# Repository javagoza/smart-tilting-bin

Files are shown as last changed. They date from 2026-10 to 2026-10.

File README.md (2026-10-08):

# Smart Tilting Bin

A refuse sorter that sees, hears and learns, built with reused materials.

A camera looks down at the object you drop in, an AI model decides which of four fractions it belongs to (packaging, paper, organic, general waste), and a rotating-tilting tray drops it into the right container. Two small motors reach four containers.

> Work in progress. This repository holds the parametric mechanical model and the simulation. It is part of my application to the element14 "My Project Is Trash" design challenge. Software and results will be added as the project advances.

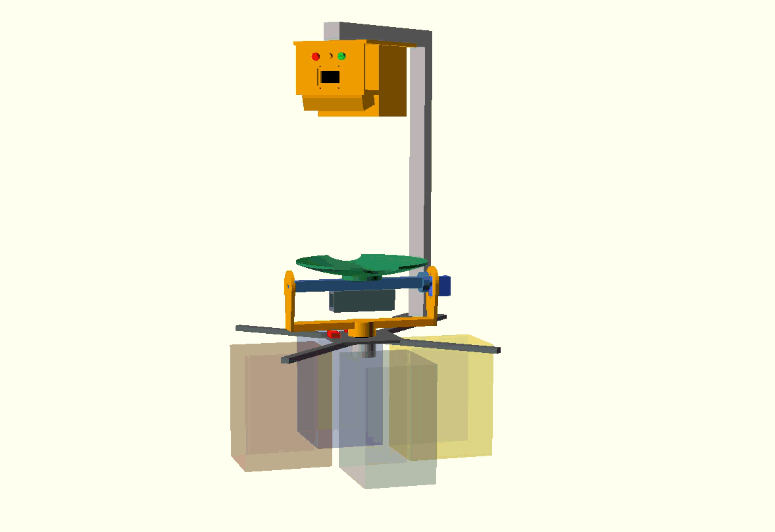
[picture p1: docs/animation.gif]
Sorting animation


## How it works

1. The user drops an object onto the tray, which rests horizontally.
2. An impact triggers a capture: a top-down Logitech C170 takes a photo and its microphone records the impact sound.
3. A Raspberry Pi CM4 classifies image and sound and maps the class to one of the four containers.
4. If the container is in line with the current tray position, the tray only tilts to +45 or -45 degrees. Otherwise the stepper first rotates the tray 90 degrees, stops, and then the tray tilts to the correct side.
5. The object slides through one of the two bites in the tray rim and falls into the container.
6. The tray returns to horizontal and LEDs and an OLED report the result.

```
               [ PAPER ]
                   |
 [ PACKAGING ] --- O --- [ ORGANIC ]
                   |
            [ GENERAL WASTE ]

 O = tray axis. At rotation 0 the tray tilts towards PAPER or
 GENERAL WASTE, at rotation 90 towards PACKAGING or ORGANIC.
```

## Mechanism

- **Base:** a fixed plate holds a 28BYJ-48 stepper (ULN2003 driver) with a vertical shaft. There is no solid disc under the tray, so objects fall freely.
- **Yoke:** a U-shaped yoke on the stepper shaft rotates between 0 and 90 degrees (two microswitches provide homing) and carries the tilt axis and an SG90 servo.
- **Tilt axis:** a horizontal beam. One end is a simple pivot and the other is coupled directly to the servo horn, so 90 degrees of servo travel gives +/-45 degrees of tilt.
- **Tray:** 150 mm, concave, with two round bites on the rim, perpendicular to the tilt axis.
- **Counterweight:** a printed holder under the beam with a sliding steel bar, so the servo hardly works at rest and the tray settles horizontal by itself.
- **Sensor support:** an "L" or arch bolted to a diagonal strut holds the camera above the tray. Its front wall faces the user and carries three LEDs, an OLED and, underneath, the IR light angle sensor aimed at the tray.

## Hardware

| Part | Role |
|---|---|
| Analog Devices EVAL-ADXL372Z | Vandalism and heavy-object protection, capture trigger, impact signature |
| Analog Devices EVAL-CN0569-PMDZ | IR gesture selection of the bin, labelling, game controller, hand detection |
| Hammond 1554X2GYCL (IP68) | Sealed enclosure for the electronics |
| CamdenBoss IND514113-LED | Green, amber and red status LEDs |
| CamdenBoss CTBP92HD/4 and CTBP93HD/4 | Pluggable terminal blocks |
| CamdenBoss CSM40500A | Limit switches for homing |

Complementary hardware (not in the kit): Raspberry Pi CM4 on a Waveshare CM4-NANO-A (or Pi 4 / Pi 5), Logitech C170, 28BYJ-48 with ULN2003, SG90 servo and an SSD1306 OLED.

## OpenSCAD model

Open `cad/smart_tilting_bin.scad` with OpenSCAD 2021.01 or later. Every dimension is a variable, so you can adapt the model to the materials you find (a salad bowl as the tray, a curtain-rod tube as the beam, and so on).

Main parameters:

| Parameter | Meaning |
|---|---|
| `part` | `"assembly"`, `"tray"`, `"beam"`, `"yoke"`, `"base"`, `"counterweight"` or `"camera_support"` (to export single STL files) |
| `yaw` | Tray rotation, 0 to 90 degrees |
| `tilt` | Tray tilt, -45 to +45 degrees |
| `animate` | `true` runs the sorting simulation of the four refuse types (View > Animate) |
| `show_bins`, `show_hw`, `show_cam` | Show containers, electronics and the camera support |
| `cam_support` | `"L"` or `"arch"` |
| `tray_d`, `dish_depth`, `bite_r` | Tray diameter, concavity and bite radius |
| `cw_bar_len` | Counterweight bar length (the console prints an estimate of the balance) |
| `cam_view_d` | Diameter of the tray area the camera must see |

The console prints the estimated balance of the tray, the camera height and the aim angle of the IR sensor.

Dimensions of the commercial parts (28BYJ-48, SG90, Logitech C170, SSD1306) are typical values, so check them against your own parts.

## Render the animation

With OpenSCAD and ffmpeg installed:

```
./scripts/render_gif.sh
```

Or with the OpenSCAD GUI: set `animate = true`, open View > Animate with 160 steps and 20 FPS, check "Dump Pictures", and turn the PNG frames into a GIF with ffmpeg.

## Reusing materials

Most of the mechanism can be built from waste: a plastic bowl or wok lid as the tray, a curtain-rod tube as the tilt beam, a cutting board or pallet wood for the base, a bottle cap as the sliding washer, a paper tube as the sensor visor, a food container lid as the LED panel, and nuts and bolts as the counterweight. Motors, servo, sensors and electronics are new.

## Status

- [x] Parametric OpenSCAD model and sorting simulation
- [ ] Mechanism build and calibration
- [ ] Electronics and wiring
- [ ] Vision classifier (offline and online)
- [ ] Sound classifier and sensor fusion
- [ ] Gesture selection, labelling and game mode
- [ ] Vandalism detection

## License

- CC BY-SA 4.0 for the CAD files 
- MIT for the code

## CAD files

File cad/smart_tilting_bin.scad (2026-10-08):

/*
 * SMART TILTING BIN - computer-vision refuse sorter
 * Rotating-tilting tray mechanism (first prototype)
 *
 * Mechanical concept
 * ------------------
 *  - Fixed BASE: a central plate holds the 28BYJ-48 stepper (vertical shaft) and
 *    4 diagonal struts towards the enclosure. There is no disc under the tray,
 *    so objects fall freely into the containers.
 *  - YOKE (rotation): a U-shaped bar fixed to the 28BYJ-48 shaft. It only turns
 *    between 0 and 90 degrees (two microswitches provide homing at those two
 *    positions) and carries the SG90 servo and the tilt axis.
 *  - BEAM + TRAY (tilt): the horizontal beam is the tilt axis. One end is a
 *    simple pivot, the other is coupled to the SG90 horn (direct drive,
 *    90 degrees of servo travel = +/-45 degrees of tilt).
 *  - The tray is concave (parabolic) and has 2 "bites" on the sides where the
 *    refuse falls (perpendicular to the tilt axis). They work as a funnel
 *    towards the container. The ends of the tilt axis keep a solid rim.
 *  - 4 containers at 0/90/180/270 degrees around the axis (translucent ghosts).
 *  - COUNTERWEIGHT: a holder under the beam with a sliding steel bar.
 *  - "L" or "arch" SUPPORT (cam_support) for the overhead Logitech C170 camera,
 *    bolted to a diagonal strut of the base. Its front wall (user side) carries
 *    3 x 8 mm LEDs, below them the SSD1306 OLED (not in the kit) with an acrylic
 *    window and, under a lower shelf, the IR light angle sensor tilted towards
 *    the tray (ir_aim). The OLED shows the gestures to perform and the IR sensor
 *    can also detect a hand approaching to drop refuse.
 *
 * Positioning logic (the +/-45 degree tilt reaches 2 containers for each yaw):
 *    yaw 0   -> tilt +/-45 reaches the containers at 90 and 270 degrees (+/-Y)
 *    yaw 90  -> tilt +/-45 reaches the containers at 0 and 180 degrees  (+/-X)
 *    If the target container is already "in front" of the current position the
 *    tray only tilts. Otherwise it rotates 90 degrees, stops and then tilts.
 *
 * Convention: positive yaw = counterclockwise seen from above.
 *             positive tilt = the +Y side goes up (refuse falls towards -Y).
 *
 * Units: mm.
 * Usage: change `part` to export single parts to STL.
 *        Set `animate = true` and use View > Animate (FPS 20, Steps 400) to run
 *        the sorting simulation of the four refuse types.
 *
 * Dimensions of the commercial parts (28BYJ-48, SG90, Logitech C170, SSD1306)
 * are typical values: check them against your own parts.
 */

// ------------------------------------------------------------------ PARAMETERS
part        = "assembly";   // "assembly","tray","beam","yoke","base","counterweight","camera_support"
yaw         = 0;            // [0:90]    tray rotation (28BYJ-48)
tilt        = 0;            // [-45:45]  tray tilt (SG90)
animate     = false;        // true: refuse deposition simulation (View > Animate)
show_bins   = true;         // ghost containers
show_hw     = true;         // motor, servo, horn, microswitches, sensors

$fn = 90;

// ------------------------------------------------ REFUSE DEPOSITION SIMULATION
// Container i sits at angle 90*i: 0=+X Packaging, 1=+Y Paper, 2=-X Organic, 3=-Y General waste
bin_names = ["Packaging","Paper","Organic","General waste"];
seq = [1,3,0,2];   // demo order: Paper, General waste (no rotation), Packaging (rotates 90), Organic (no rotation)

function yaw_for(i)  = (i==0 || i==2) ? 90 : 0;     // containers on X -> yaw 90
function tilt_for(i) = (i==0 || i==3) ? 45 : -45;   // tilt + : refuse falls towards the local -Y side
function clamp01(x)  = min(max(x,0),1);
function ease(x)     = let(c = clamp01(x)) c*c*(3-2*c);

// Timeline: $t in [0,1) -> 4 refuse items, each with its phases (u in [0,1)):
//  0.00-0.12 the item drops onto the tray        0.12-0.25 computer vision (identifies it)
//  0.25-0.40 rotation of 90 deg if needed (stop) 0.40-0.56 tilt to +/-45 deg
//  0.52-0.68 the item slides through the bite    0.68-0.86 falls into the container
//  0.72-0.88 the tray returns to 0 deg           0.90-1.00 (last item) yaw returns to 0 (rest)
sim_k   = min(floor($t*4), 3);
sim_u   = $t*4 - sim_k;
sim_bin = seq[sim_k];
sim_prev_yaw = sim_k==0 ? 0 : yaw_for(seq[sim_k-1]);
sim_yaw_raw  = sim_prev_yaw + (yaw_for(sim_bin)-sim_prev_yaw)*ease((sim_u-0.25)/0.15);
sim_yaw  = sim_k==3 ? sim_yaw_raw*(1-ease((sim_u-0.90)/0.10)) : sim_yaw_raw;
sim_tilt = tilt_for(sim_bin)*(ease((sim_u-0.40)/0.16) - ease((sim_u-0.72)/0.16));

yaw_e  = animate ? sim_yaw  : yaw;
tilt_e = animate ? sim_tilt : tilt;

// Refuse kinematics
orad   = 8;                                  // approximate size of each refuse item
function zloc(d) = beam_h/2 + hub_h + zs(d) + tray_t + orad;
function rx(p,a) = [p[0], p[1]*cos(a)-p[2]*sin(a), p[1]*sin(a)+p[2]*cos(a)];
function rz(p,a) = [p[0]*cos(a)-p[1]*sin(a), p[0]*sin(a)+p[1]*cos(a), p[2]];
function world_pos(yw,tl,lp) = rz(rx(lp,tl)+[0,0,Zt], yw);
function rest_pos(i) = [96*cos(90*i), 96*sin(90*i), -140+orad];

function item_pos(j) =
    j > sim_k ? undef :
    j < sim_k ? rest_pos(seq[j]) :
    (sim_u < 0.12) ? world_pos(yaw_e, tilt_e, [0,0, zloc(0) + 100*(1-pow(sim_u/0.12,2))]) :
    (sim_u < 0.52) ? world_pos(yaw_e, tilt_e, [0,0, zloc(0)]) :
    (sim_u < 0.68) ?
        (let(s = (sim_u-0.52)/0.16,
             d = d_exit*s*s,
             sg = tilt_for(sim_bin) > 0 ? -1 : 1)
            world_pos(yaw_e, tilt_e, [0, sg*d, zloc(d)])) :
        (let(sg = tilt_for(sim_bin) > 0 ? -1 : 1,
             p0 = world_pos(yaw_for(sim_bin), tilt_for(sim_bin), [0, sg*d_exit, zloc(d_exit)]),
             pr = rest_pos(sim_bin),
             s  = clamp01((sim_u-0.68)/0.18))
            [p0[0]+(pr[0]-p0[0])*s, p0[1]+(pr[1]-p0[1])*s, p0[2]+(pr[2]-p0[2])*s*s]);

module item_shape(i) {
    if      (i==0) color("gold")      cylinder(d=14, h=16, center=true);              // can (packaging)
    else if (i==1) color("royalblue") rotate([25,35,10]) cube(13, center=true);       // crumpled paper
    else if (i==2) color("firebrick") sphere(r=orad);                                 // fruit (organic)
    else           color("gray")      sphere(r=orad, $fn=6);                          // general waste
}

module items() {
    for (j=[0:3]) {
        p = item_pos(j);
        if (!is_undef(p)) translate(p) item_shape(seq[j]);
    }
}

// Tray
tray_d     = 150;
R          = tray_d/2;
tray_t     = 3;      // thickness
dish_depth = 14;     // depth of the concavity (parabola)
bite_r     = 22;     // radius of each bite
bite_off   = 4;      // offset of the bite centre beyond the rim
hub_d      = 46;     // base that fixes the tray to the beam
hub_h      = 4;

// Tilt axis
Zt     = 60;         // height of the tilt axis above the base plate
beam_w = 14;
beam_h = 12;

// Yoke
AX    = 83;          // inner face of the arms (|x|)
arm_t = 4;           // arm thickness (= thickness for the SG90 ears)

// Microswitches (rotation homing). Angle (on the base) where each one is pressed.
// Cam mounted at 90 deg at yaw=0 -> switch A at 90 deg (yaw 0), switch B at 180 deg (yaw +90)
sw_angles = [90, 180];

// Radius where the tray opens through the bite (the refuse leaves the tray here).
// Must come after R, bite_r and bite_off (OpenSCAD evaluates variables in order).
d_exit = R + bite_off - bite_r - 1;

// ------------------------------------------------------------------ COUNTERWEIGHT
// Printed holder under the beam + 15x15 mm steel bar (it slides through a
// through-cavity and is locked with an M3 grub screw). It balances the tray so
// the SG90 hardly works at rest.
cw_len     = 72;     // holder length (X axis)
cw_out     = 24;     // outer section (Y and Z)
cw_cav     = 16;     // through cavity
cw_bar_len = 24;     // steel bar length (adjust with a scale; must be < 56)
rho_pla    = 1.24e-3;   // g/mm3 (approx. PETG/PLA)
rho_steel  = 7.85e-3;   // g/mm3

// Rough estimate of the moments about the axis (g*mm)
m_plate  = (PI*R*R - 2*0.45*PI*bite_r*bite_r)*tray_t*rho_pla;
z_plate  = beam_h/2 + hub_h + dish_depth/2 + tray_t/2;
m_hub    = PI*pow(hub_d/2,2)*(hub_h+tray_t)*rho_pla;
z_hub    = beam_h/2 + (hub_h+tray_t)/2;
mom_tray = m_plate*z_plate + m_hub*z_hub;
m_holder = (cw_len*cw_out*cw_out - cw_len*cw_cav*cw_cav)*rho_pla;
z_cw     = beam_h/2 + cw_out/2;
mom_cw   = (m_holder + 15*15*cw_bar_len*rho_steel)*z_cw;
bar_ideal = max(0, (mom_tray - m_holder*z_cw)/(z_cw*15*15*rho_steel));
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

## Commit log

2026-10-08 Added first openscad prototype and animation.
    [smart_tilting_bin.scad]
2026-10-10 Create readme.md for gesture sensor driver
    Add readme for EVAL-CN0569-PMDZ Gesture Sensor Driver
2026-10-12 Enhance readme with setup and usage instructions
    Added detailed instructions for hardware wiring, installation, and usage of the SG90 servo library.
2026-10-12 Add demo script for SG90 Servo Motor control
    This demo script controls an SG90 servo motor, sweeping it from 0 to 180 degrees and back, using a Raspberry Pi.
2026-10-12 Add SG90 Servo Motor Controller Library
    This library provides a class to control SG90 servo motors using PWM on Raspberry Pi. It includes methods to set and get angles, detach the servo, and cleanup GPIO settings.
2026-10-13 Add README for 28BYJ-48 Stepper Motor Driver
    Added comprehensive documentation for the 28BYJ-48 stepper motor driver library, including features, installation instructions, and code examples.
